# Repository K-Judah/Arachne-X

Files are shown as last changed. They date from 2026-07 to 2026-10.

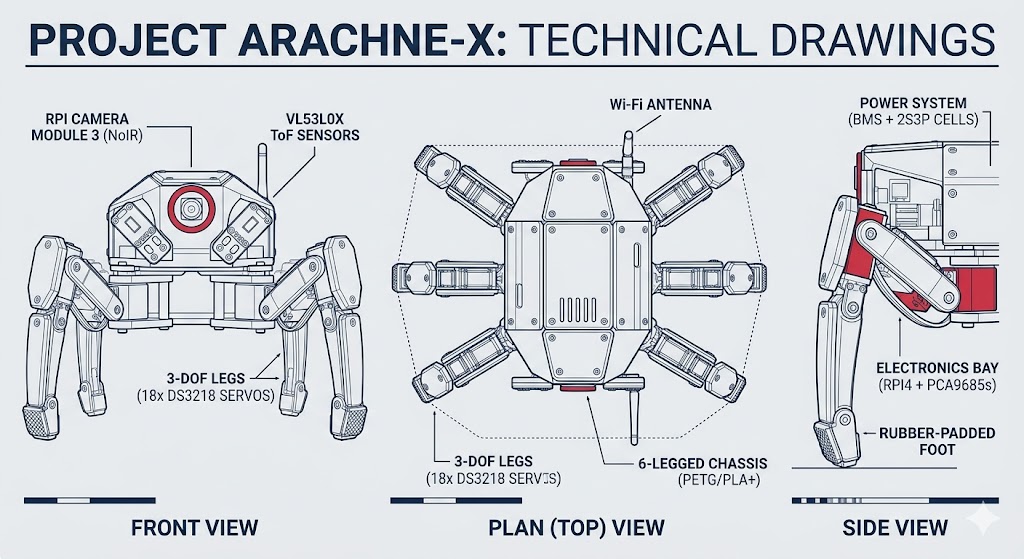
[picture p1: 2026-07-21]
Images/d1f36d08-249d-48b4-a907-852d1e6383c1.jpg

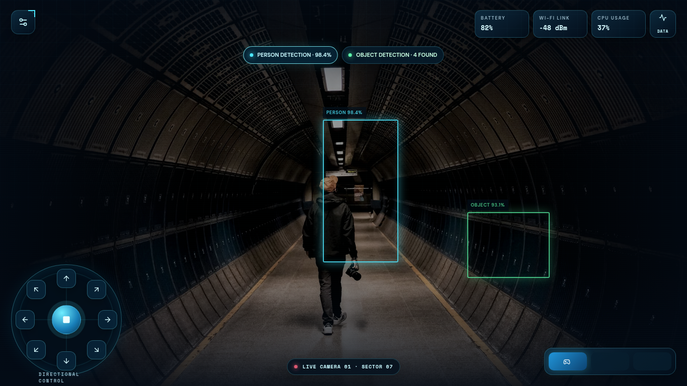
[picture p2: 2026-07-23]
Images/Arachne-X Futuristic Robotics App UI.png

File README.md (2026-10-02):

# Arachne-X

Arachne-X is a six-legged autonomous spider robot being developed as a long-term robotics and AI project.

## Goals

- Autonomous navigation
- AI vision
- Remote control
- Object detection
- Person tracking
- Computer vision
- Robotics research

## Hardware

- Raspberry Pi 4B
- ESP32-WROOM-32U based development board (exact board variant TBD)
- 2 PCA9685 servo controllers
- 18 MG996R servos: 6 legs with 3 DOF per leg
- Camera-based computer vision (camera model TBD)
- IMU and ToF sensors are planned options; selection and integration TBD

## Current Status

🚧 Single-leg prototype in development.

The July 24 progress log is historical: subsequent remote work added tibia and chassis models and updated coxa/femur and leg assembly assets. Their physical fit, range of motion and calibration still require verification. A [host-testable ESP32 firmware foundation](Firmware/README.md) provides joint configuration, validation and simulated actuator control. [Command/telemetry protocol v1](protocol/PROTOCOL.md) and a [Python reference client](Raspberry_Pi/README.md) now support simulated Pi/ESP32 exchanges. **Physical servo output is intentionally unavailable.** The repository also contains [OpenCV vision prototypes](Computer_Vision/README.md) and a [dashboard draft](Dashboard/dashboard.html). These are not connected to protocol v1; the dashboard uses a separate HTTP /cmd assumption, and vision steering labels are display output. Full Pi control services and gait/IK remain unimplemented.

## Software Planning

- [Proposed software architecture](docs/SOFTWARE_ARCHITECTURE.md)
- [Calibration records and simulated persistence](docs/CALIBRATION_RECORDS.md)
- [Repository audit and development plan](docs/DEVELOPMENT_PLAN.md)
- [Instructions for coding agents](AGENTS.md)

The hardware list above is the current planning baseline. Existing master specifications and mechanical documents retain historical DS3218/DevKit V1 references, and the old component list specifies one PCA9685. Those references need reconciliation with the current baseline; they do not establish compatibility with the evolving CAD. Mechanical dimensions, wiring, calibration and power-system values remain TBD until documented and validated.

## Team

### Judah
Project Founder & Lead Systems Engineer

Responsible for:
- System Architecture
- Mechanical Design
- Hardware Integration
- Project Management

### Bilaal
Co-Developer

Responsible for:
- Software Development
- Firmware
- AI
- Dashboard Development

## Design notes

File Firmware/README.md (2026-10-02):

# ESP32 firmware foundation

**Physical servo actuation is intentionally unavailable. This is not production-ready robot firmware.** No PCA9685, I2C, GPIO, PWM or transport driver exists. The ESP32 entry point constructs a disabled controller with unresolved configuration and returns. Building does not flash hardware, and PlatformIO upload targets are rejected. No hardware is needed for any test below.

The baseline is six three-joint legs, 18 MG996R servos and two PCA9685 controllers, with a Raspberry Pi 4B eventually supplying intent to an ESP32-WROOM-32U based board. The exact development board remains TBD. A hardware-independent [protocol v1](../protocol/PROTOCOL.md) now connects a [Python reference client](../Raspberry_Pi/README.md) to the host-tested C++ endpoint. Its component is registered for the ESP32 build but is not attached to a physical transport or boot task.

## Layout and build decision

```text
Firmware/
  platformio.ini          pinned ESP-IDF cross-compilation environment
  requirements-build.txt  pinned PlatformIO frontend
  CMakeLists.txt          host/ESP-IDF build selection
  control_core/
    include/arachne/      joint IDs, configuration, output/clock interfaces, actuator API
    src/                  portable validation and actuator implementation
  esp32/main/             inert app_main; no hardware drivers
  protocol/               bounded wire codec, transport interface and dispatcher
  calibration/            versioned record codec, persistence contract and host memory storage
  test/
    support/              fake output, fake clock, synthetic calibration, test runner
    test_control.cpp      simulation and validation tests
    test_locked.cpp       firmware-lock tests, including the actual app_main
  scripts/deny_upload.py  rejects PlatformIO upload/program targets
```

The existing architecture specifies ESP-IDF and separate esp32/control_core directories. We retain both, using PlatformIO as an ESP-IDF dependency/build frontend, not switching to Arduino. Host CMake/CTest compiles the same core without downloading an embedded SDK or a test framework. The Python reference client lives outside the firmware project in Raspberry_Pi/; a full Pi robot service is not implemented.

## Run host tests

Prerequisites: CMake 3.20 or newer, Python 3.11+ (standard library only) and a C++17 compiler (GCC/Clang, or Visual Studio C++ Build Tools and a Windows SDK). The host tests have no external library dependencies. From the repository root:

```sh
cmake -S Firmware -B Firmware/build-host -DARACHNE_HOST_TESTS=ON -DCMAKE_BUILD_TYPE=Release
cmake --build Firmware/build-host --config Release --parallel
ctest --test-dir Firmware/build-host -C Release --output-on-failure
```

On Windows, use a developer terminal if the tools are not on PATH. CMake can use its default Visual Studio generator; do not reuse a build directory generated for a different compiler. Use `ctest --test-dir Firmware/build-host -C Release -V` to see every named test case. Tests use runtime checks that remain active in Release builds, not C/C++ assertions removed by NDEBUG. Project sources and tests compile with warnings treated as errors.

`control_tests` links the simulation-enabled core; `locked_tests` separately compiles the same core with simulation disabled, exactly as firmware does. The latter proves that even complete synthetic configuration and a fake backend cannot enable the locked build. `protocol_tests` and `protocol_locked_tests` exercise the codec/dispatcher. A Python CTest entry runs unit tests and actual Python-to-C++ endpoint exchanges through two host-only bridge executables. Two additional suites, calibration_tests and calibration_locked_tests, cover persistence and restored-configuration safety, for seven suites total. See [calibration records](../docs/CALIBRATION_RECORDS.md) for the schema, lifecycle and validation results. Configuration also verifies that ESP32 flags combined with simulation enablement fail compilation for the expected guard diagnostic. The Python suite verifies the unchanged upload guard. The GitHub Actions workflow runs all host tests on Linux and Windows and separately cross-compiles the ESP32 application; no physical devices are used.

## Cross-compile only

Use Python 3.11 and install the pinned frontend in a virtual environment if PlatformIO is not already available:

```sh
python -m pip install -r Firmware/requirements-build.txt
pio run --project-dir Firmware --environment esp32_compile_only
```

The environment pins PlatformIO Core 6.1.19, Espressif32 platform 6.10.0, ESP-IDF package 3.50400.0 (ESP-IDF 5.4.0) and Xtensa compiler 14.2.0+20241119. First compilation downloads SDK/tool packages and requires internet access. Other build helpers are resolved by that platform release. See the [PlatformIO ESP-IDF build documentation](https://docs.platformio.org/en/latest/frameworks/espidf.html) and [pinned platform manifest](https://github.com/platformio/platform-espressif32/blob/v6.10.0/platform.json).

`esp32dev` is a generic ESP32 **compile-only surrogate**, not a claim that the installed board is a DevKit V1 or has the manifest's flash layout. No robot GPIO, I2C address, oscillator frequency or production calibration is assigned. Actual board/flash settings must be verified before a later deployment phase. Do not flash the generated image. Upload is intentionally blocked; direct external flashing tools are outside this project's safeguards.

## Joint identity and configuration

Strong enums define `Leg::{LF,LM,LR,RF,RM,RR}`, `JointKind::{Coxa,Femur,Tibia}` and all 18 logical `JointId` values, from `LF_Coxa` through `RR_Tibia`. `Unknown` is a rejected sentinel used by default-constructed records, not an additional joint. IDs follow the architecture's leg-major order; names such as `LF.coxa` are available for diagnostics. Bounds-checked helpers reject invalid leg/joint enums.

Each `JointConfiguration` links one logical ID to a `Wiring` record (controller A/B and channel) and a separate `Calibration` record. Configuration slot order does not determine identity. The only production factory, `unconfigured_robot()`, contains the 18 identities but leaves all wiring, direction, angles and pulses as `std::nullopt`, with `Uncalibrated` state. There is no guessed mapping or default calibration in firmware. The architecture's channel table remains a proposal, not installed wiring.

Calibration fields use explicit radians and microseconds: minimum angle, neutral angle/offset, maximum angle, minimum pulse, neutral pulse and maximum pulse, plus Normal/Inverted direction and calibration state. Neutral must lie strictly inside both ranges so the two interpolation segments are defined. `neutral_rad` is the logical joint coordinate at the measured neutral pulse; it is not implicitly zero. Inversion reverses pulse endpoints while preserving measured neutral. The controller rejects targets outside the calibrated logical range rather than silently clamping them.

`validate()` returns a bounded `ValidationReport`, with an error code, offending configuration slot where applicable, logical joint, and a human-readable `describe()` message. It reports missing/duplicate/invalid joints, missing/invalid controllers and channels, duplicate controller/channel pairs, missing calibration fields, uncalibrated/invalid state, invalid direction, non-finite values, reversed/equal ranges and neutral values outside the strict interior. The PCA9685's 0-15 channel domain is a device constraint, not a chosen harness assignment. The same channel number on A and B is valid. Any invalid joint blocks enabling the entire system.

Only test code contains a complete configuration. Its deliberately asymmetric numbers are **synthetic arithmetic fixtures, not MG996R pulse ranges or robot joint limits**. Test support is outside the firmware component and compilation rejects inclusion on ESP32. Geometry, I2C addresses, GPIO assignments, PWM frequency, mechanical limits and measured offsets all remain TBD; fields not consumed by this phase are deliberately absent rather than given misleading defaults. Geometry schemas and physical storage adapters remain future work before physical motion. The portable calibration record and simulated atomic persistence are implemented; all physical values remain unresolved.

## Safety boundary and interfaces

`ServoOutput` accepts a typed `PulseCommand` (logical joint, controller, channel, pulse in microseconds, monotonic timestamp). `Clock` supplies optional monotonic microseconds; unavailable time fails closed. `FakeOutput` records attempts/accepted commands and can inject failure; `FakeClock` supplies deterministic time. `DisabledOutput` rejects every write without touching hardware. This phase does not convert pulses to PCA9685 counters or configure PWM frequency.

`ActuatorSystem` copies configuration into an immutable snapshot. Construction and `start()` issue no output. State begins `Disabled`; only explicit `enable_simulation()` in a host simulation build can transition to `SimulationEnabled`. That method requires complete valid configuration, an explicitly simulated backend and an available clock. Enable itself sends nothing. `disable()` and `start()` block subsequent commands; they never move to neutral or replay a previous command.

Firmware builds contain no enabling path. Defining `ARACHNE_HOST_SIMULATION` together with ESP-IDF's `ESP_PLATFORM` produces a compile error. The host simulation target alone defines that macro. There is no runtime switch, calibration flag or configuration value that unlocks the ESP32 build. A backend reporting Physical or Unavailable is rejected even in simulation. Test fakes have no hardware dependencies.

Invalid direct actuator targets, invalid runtime backend domain, clock loss/rollback and failed writes latch `Fault`; subsequent commands and enable requests fail. Protocol preflight uses the side-effect-free `validate_target()` to reject an entire invalid request before actuator calls; `emergency_stop()` explicitly latches Fault. Start/disable cannot clear that fault. For a fresh offline test session, construct a new controller; a production recovery protocol is not yet implemented. The actuator API is single-thread-owned and must not be called concurrently. No timing loop, velocity limiter, physical watchdog, IK or gait is implemented. The protocol endpoint implements configurable communication/motion deadlines only when its owner polls/ticks it; those are not a physical watchdog.

Stopping future software writes is **not** a physical emergency stop, power disconnect or guarantee that an externally powered PCA9685 has stopped an old waveform. This phase must never be used to control powered actuators. OE/cutoff wiring and a measured stop policy are prerequisites for any future hardware driver.

## Future calibration

After the electrical design, cutoff circuit and actual harness are verified, support the mechanism and calibrate one joint at a time: confirm channel identity, establish neutral before fitting the horn, measure direction and conservative collision-free endpoints, and validate the installed joint. Never blindly sweep assumed MG996R endpoints. Record servo identity, CAD/geometry revision, measurement method and date; use the versioned calibration record and atomic storage contract to retain approved evidence. A durable physical storage adapter and a verified approval process remain future work. Servo/horn replacement or changed geometry invalidates the affected record. The current `Calibrated` enum is sufficient for synthetic tests, not evidence of physical certification.

## Foundation verification snapshot (commit 7d2f00e, 2026-10-02)

- Windows x64, CMake 4.3.1-msvc1, MSVC 19.51.36260.0: Release configuration and compilation passed with /W4 /WX; no compiler warnings or errors.
- CTest: 2/2 executables passed, comprising 33/33 control cases and 4/4 locked-build cases (37 total). The actual ESP32 entry-point source was also compiled and run against the locked host core.
- CMake's negative compile check rejected ESP32 plus simulation flags with the intended diagnostic. Five isolated Python checks of the upload guard accepted normal build targets and rejected upload/uploadfs/program without invoking devices.
- PlatformIO 6.1.19 cross-build was attempted but interrupted during the first Xtensa toolchain download (380,779,175-byte archive). A separate 1 MiB transfer took 83.5 seconds. No ESP32 image was compiled or verified; rerun the documented cross-build when the SDK/toolchain download is available. The CI workflow is committed but has not been run on GitHub in this session.
- Protected CAD/Assembly/Images/Videos files passed before/after SHA-256 comparison. No physical hardware was used. These results do not establish electrical, mechanical or real-time safety.

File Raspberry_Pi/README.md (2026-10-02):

# Raspberry Pi protocol reference client

This source-only Python 3.11+ package implements the hardware-independent [protocol v1](../protocol/PROTOCOL.md) client. It is not a robot service, planner, physical transport or actuator driver. It has no third-party runtime/test dependencies; no package installation is needed to test it.

`arachne_protocol/wire.py` supplies bounded COBS/CRC framing and a stream parser. `transport.py` defines the nonblocking transport contract and bounded in-memory pairs. `client.py` implements handshake, heartbeat, status, explicit simulation enable requests, disable, single/multi targets and E-stop. Clients never enable automatically or retry requests. Physical permission remains false and a response claiming otherwise is rejected.

Add `Raspberry_Pi/` to Python's import path, then supply an implementation of `Transport` to `Client`. A memory pair alone needs its peer to service requests; it does not simulate firmware by itself. The test harness runs the actual C++ endpoint instead of a second Python server model. The current synchronous client expects a serviced reply when it reads; async IO/deadline scheduling belongs in a later transport adapter.

The API is `hello()`, `heartbeat()`, `status()`, `enable()`, `disable()`, `set_joint(joint_id, radians)`, `set_multi([(joint_id, radians), ...])`, and `emergency_stop()`. Accepted command results expose `accepted`, `simulation_enabled`, and `physical_permission` separately. NACKs raise `RemoteError` with an `Error` code and state/fault outcome. No target values are suggested here because actual geometry, travel and calibration remain TBD.

Run all previous firmware tests, new protocol tests and Python/C++ integration tests from the repository root:

```sh
cmake -S Firmware -B Firmware/build-host -DARACHNE_HOST_TESTS=ON -DCMAKE_BUILD_TYPE=Release
cmake --build Firmware/build-host --config Release --parallel
ctest --test-dir Firmware/build-host -C Release --output-on-failure
```

The Python test command is also visible with `ctest --test-dir Firmware/build-host -C Release -N -V`. It needs paths to the two built protocol bridge executables; neither bridge connects to hardware. CTest limits the integration test duration. Physical transport, authentication, production timing, boot-session uniqueness and configuration revision persistence remain TBD.

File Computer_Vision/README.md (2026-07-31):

# ARACHNE-X Mk I Vision

> Computer Vision subsystem for the ARACHNE-X Autonomous Hexapod Robot.

---

## Overview

The ARACHNE-X Vision System is responsible for allowing the robot to perceive, interpret, and react to its environment in real time.

The long-term objective is to develop an autonomous vision system capable of:

- Object detection
- Object tracking
- Human detection
- Obstacle recognition
- Target following
- Autonomous navigation
- Integration with the robot's AI system

Development is currently being carried out in Python using OpenCV before deployment onto the Raspberry Pi.

---

# Current Features

## Camera Initialisation

- Webcam initialisation
- Camera availability checking
- Live video streaming
- Graceful shutdown

---

## Vision HUD

A custom Heads-Up Display (HUD) was developed featuring:

- ARACHNE-X Mk I title
- FPS counter
- Camera resolution
- Camera status
- Operator name
- Central aiming reticle

---

## Frame Processing

Each captured frame is processed in real time by:

1. Capturing image
2. Converting BGR → HSV colour space
3. Detecting selected colours
4. Finding object contours
5. Drawing object boundaries
6. Calculating object centre
7. Estimating object position
8. Producing steering decisions

---

## Colour Detection

Implemented colour-based object detection using HSV filtering.

Current supported colour:

- Red

Processing pipeline:

```
Camera
    ↓
Capture Frame
    ↓
Convert BGR → HSV
    ↓
HSV Thresholding
    ↓
Binary Mask
```

---

## Object Detection

Implemented contour-based object detection using:

- `cv2.findContours()`
- `cv2.boundingRect()`
- `cv2.contourArea()`

Each detected object displays:

- Bounding box
- Object centre
- Object coordinates

Small contours are filtered to remove image noise.

---

## Object Tracking

For each detected object:

- Calculate centre coordinates
- Display coordinates
- Draw centre marker

Example:

```
Object Centre:
(318, 241)
```

---

## Robot Steering Logic

The vision system compares the detected object's centre with the camera's centre.

```
Error = Object X - Frame Centre X
```

Based on this error, the robot decides whether to:

- Turn Left
- Turn Right
- Go Straight

Current steering thresholds:

```
Error > 40      → Turn Right
Error < -40     → Turn Left
Otherwise        → Go Straight
```

---

## Current Vision Pipeline

```
Camera
    │
    ▼
Capture Frame
    │
    ▼
Convert to HSV
    │
    ▼
Create Colour Mask
    │
    ▼
Find Contours
    │
    ▼
Remove Noise
    │
    ▼
Calculate Bounding Box
    │
    ▼
Find Object Centre
    │
    ▼
Compare With Camera Centre
    │
    ▼
Determine Steering Direction
    │
    ▼
Display HUD
```

---

# Technologies Used

- Python 3.14
- OpenCV
- NumPy

---

# Current Project Structure

```
Computer_Vision/

│
├── Lessons/
│   ├── Camera_Test.py
│   ├── Pixel_Reader.py
│   ├── HSV_Explorer.py
│   ├── Colour_Detection.py
│   ├── Object_Tracking.py
│   └── MkII_Vision.py
│
├── Images/
│
├── Videos/
│
└── README.md
```

---

# Future Development

The following features are planned:

## Motion Detection

- Background subtraction
- Intruder detection
- Patrol mode

---

## Face Detection

- Human face recognition
- Operator tracking

---

## AI Object Detection

Integration of YOLO for detection of:

- Person
- Backpack
- Bottle
- Chair
- Laptop
- Phone
- Door
- Animals
- Vehicles

---

## Multi-Object Tracking

Track multiple objects simultaneously.

---

## Depth Estimation

Estimate target distance using camera vision.

---

## Raspberry Pi Deployment

Port the complete vision system to the Raspberry Pi onboard computer.

---

## Robot Integration

Connect vision output to:

- ESP32 controller
- Servo control system
- Navigation system
- AI decision engine

---

# Long-Term Goal

The ARACHNE-X Vision System will eventually serve as the robot's primary perception module, enabling autonomous exploration, obstacle avoidance, object recognition, and intelligent interaction with its surroundings.

---

## Project Status

**Current Stage:** Early Development (Mk II Vision)

### Completed

- Camera interface
- Live HUD
- HSV colour processing
- Colour segmentation
- Contour detection
- Bounding boxes
- Object tracking
- Steering decision logic

### In Progress

- Motion detection
- Human detection
- AI object recognition

---

Developed as part of the **ARACHNE-X Autonomous Hexapod Robot Project**.

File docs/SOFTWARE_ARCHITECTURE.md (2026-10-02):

# Proposed software architecture

Status: architecture proposed 2026-10-02; the [firmware foundation](../Firmware/README.md) implements portable joint/configuration validation and host-only simulated actuator control. [Protocol v1](../protocol/PROTOCOL.md) now implements a bounded command/telemetry codec, dispatcher and Python reference client. The ESP32 application remains inert and physical output is unavailable. Gait, IK, hardware drivers and full Pi services below remain proposals. See [development plan and repository audit](DEVELOPMENT_PLAN.md) for evidence and sequencing. Existing Documents/ files remain engineering history; this proposal uses the hardware assumptions supplied for the audit.

## Hardware and configuration contract

| Item | Current baseline |
| --- | --- |
| Legs and joints | 6 legs, coxa yaw / femur pitch / tibia pitch; 18 joints |
| Actuators | 18 MG996R servos |
| High-level computer | Raspberry Pi 4B |
| Low-level computer | ESP32-WROOM-32U based development board; exact board/pinout TBD |
| PWM controllers | 2 PCA9685 boards; actual addresses and wiring TBD |
| Vision | Camera-based; camera model, interface and calibration TBD |
| Mechanics | Evolving CAD; link lengths, mounting transforms, joint zeros and motion envelope TBD |
| Power and sensing | Rails, battery, current budget, cutoff circuit, IMU/ToF selection and feedback sensors TBD |

PETG, M3 hardware and a below-5-kg target appear in the historical mechanical requirements. They are design requirements, not measured properties of a completed MG996R robot. Servo fit, torque/load capacity and clearances require revalidation. Do not infer link lengths from filenames or use generic servo travel/pulse specifications as calibration.

## Responsibilities and data flow

```text
Browser dashboard <-> Pi API / telemetry service <-> command arbiter
Camera -> vision worker -> timestamped observations -> mission controller
Mission controller ---------------------------------> command arbiter
command arbiter <-> serial link <-> ESP32 protocol / safety supervisor
                                   -> gait -> foot targets -> leg IK
                                   -> joint limiter -> calibration -> PCA9685 x2
                                   -> 18 servos
```

The Pi sends bounded motion intent, not continuous PWM writes. The ESP32 maintains timing and independently rejects unsafe/stale requests. Vision cannot directly drive motors. Manual and autonomous sources share one exclusive control lease; stop/fault handling overrides both. A Pi crash must not leave an indefinite command active.

Proposed stack: ESP-IDF with C++ portable control components on ESP32; Python packages for Pi services and vision; TypeScript browser UI. Select and pin supported versions when scaffolding, after confirming the exact board and Pi OS. Start with simple processes and typed contracts; defer ROS integration until navigation needs justify it.

## Proposed repository layout

```text
Firmware/esp32/           ESP-IDF application, board adapters, component tests
Firmware/control_core/   portable safety, kinematics, gait and joint logic
Raspberry_Pi/            Python command arbiter, serial client, API and missions
Computer_Vision/         camera adapters, inference workers, replay and evaluation
Dashboard/              browser application and UI tests
protocol/               versioned wire specification, schemas and golden vectors
config/                 geometry, wiring and calibration schemas/examples
simulation/             fake plant, visualizer and scenario runner
tests/integration/      Pi/ESP32 contract and fault-injection scenarios
docs/                   software decisions, setup and validation procedures
Documents/              existing engineering records (preserved)
```

The audit created docs/. The firmware foundation added Firmware/esp32/, Firmware/control_core/ and Firmware/test/, with PlatformIO wrapping the specified ESP-IDF framework and CMake/CTest for independent host tests. The generic ESP32 build target is compile-only until the exact board is identified; physical enable is compiled out. The [calibration record schema and simulated persistence](CALIBRATION_RECORDS.md) are implemented. Geometry schemas, physical storage adapters and the complete safety state machine remain future work. Keep existing Ai/ and Feature/ placeholders until a separate consolidation change. Avoid parallel implementations in Ai/ and Computer_Vision/.

## ESP32 firmware and PCA9685 output

Use a fixed-period motion task driven by a monotonic clock. Its period, command refresh budget and watchdog thresholds are TBD until measured. Protocol parsing and telemetry run outside the motion task with bounded queues and payload sizes. Never block motion on logging or network activity. One component owns I2C; report write failures and deadline misses to the safety supervisor.

The pipeline accepts a desired body motion/posture, updates gait phase, computes six foot targets, solves IK, checks all 18 joints, applies rate limits, then converts angles to calibrated pulse widths. Reject an invalid full target before any output writes. Stage a complete output frame; two boards cannot be assumed to update atomically, so measure skew and fault on partial-write failure rather than reporting successful motion.

The PCA9685 adapter owns board discovery against configured identities, frequency setup, pulse-to-counter conversion and output-enable behavior. Account for measured oscillator/frequency error. Servo PWM frequency and approved pulse bounds are TBD bench values. Keep PWM carrier frequency separate from gait/control update frequency. Do not silently remap channels when a board is missing. Unused channels stay disabled. Proposed OE gating needs verified wiring and a defined boot/reset state before hardware tests; disabling PWM is not the same as disconnecting servo power.

## Stable 18-joint mapping

Use the robot's forward direction, never the camera image, to name left/right. Proposed IDs are stable software identities. This table is a proposed harness allocation, not verified wiring; addresses, pinouts, polarity and installed mapping remain TBD until continuity and single-joint tests pass. Each controller uses nine channels so all three joints of a leg remain together.

| Leg | IDs: coxa, femur, tibia | Proposed board | Proposed channels |
| --- | --- | --- | --- |
| Left front (LF) | 0, 1, 2 | A | 0, 1, 2 |
| Left middle (LM) | 3, 4, 5 | A | 3, 4, 5 |
| Left rear (LR) | 6, 7, 8 | A | 6, 7, 8 |
| Right front (RF) | 9, 10, 11 | B | 0, 1, 2 |
| Right middle (RM) | 12, 13, 14 | B | 3, 4, 5 |
| Right rear (RR) | 15, 16, 17 | B | 6, 7, 8 |

Use names such as LF.coxa in configuration and logs. Validate exactly 18 unique joints, unique board/channel pairs, valid channel ranges, two distinct configured board identities and complete per-joint calibration. Channels 9-15 on each board are reserved/disabled. Do not assume mirrored legs have identical servo signs.

## Calibration and geometry

The current portable calibration subset is specified in [CALIBRATION_RECORDS.md](CALIBRATION_RECORDS.md): CRC-checked records, explicit revision/provenance checks, staged atomic publication and immutable snapshots. Existing actuator and protocol guards are unchanged; storage operations disarm and never auto-enable. The wider geometry and physical calibration process below remains future work.

Separate three versioned configuration records:

- Geometry: robot/CAD revision, source measurements, three link lengths, six body-to-leg transforms, joint axes, zero conventions, permitted workspace and collision constraints. Physical values TBD.
- Wiring: board identities/addresses, ESP32 pin assignments, named joint-to-channel map and output-disable wiring. Physical values TBD.
- Calibration: servo identity and installed joint, direction, neutral offset, validated angle-to-pulse points, pulse and angle bounds, velocity/acceleration limits, date and method. Physical values TBD.

Prefer a measured monotonic piecewise-linear angle-to-pulse curve when a simple offset/scale is inadequate. Reject non-finite, non-monotonic or incomplete records. Validate the configuration offline and again on the ESP32; transmit an immutable version/hash and refuse arm on mismatch. Persist validated records atomically with integrity checks; interrupted writes must leave a previous valid record or a disarmed fault, never partial calibration.

Calibration is a deliberate service mode: support the mechanism, verify supply/cutoff and channel identity, operate one joint at a time with restricted pulses, establish neutral before horn attachment, measure direction and conservative usable endpoints, then verify the installed joint without collision. Never sweep blindly to physical stops. Replacing a servo/horn or changing CAD invalidates affected calibration/geometry until rechecked. Raw PWM commands are excluded from normal operation.

## Kinematics and gait

Proposed body frame: right-handed, +X forward, +Y left, +Z up; use metres, radians, seconds and explicit frame IDs. Define each leg frame at its coxa mount using a configured rigid transform. Define positive joint angles by the right-hand rule about documented joint axes; servo electrical direction belongs in calibration.

Provide pure forward/inverse kinematics functions with geometry inputs and structured results: solution, unreachable, singular or joint-limit violation. A yaw plus planar two-link analytic solver is appropriate only after CAD confirms that geometry; otherwise use a model matching measured offsets/axes. Choose the solution branch nearest the previous valid pose with continuity constraints. Never hide unreachable targets by broadly clamping trigonometric arguments; allow only documented floating-point tolerance. Reject invalid motion and enter the tested stop policy. Test FK/IK round trips, mirror transforms, workspace edges, singularities and branch continuity using synthetic fixtures clearly separated from physical configuration.

Gait generation owns stance/swing scheduling, phase, bounded foot trajectories and transitions between stand, controlled stop and walking. Start with a slow crawl and explicit support-margin checks using a measured or conservatively bounded centre of mass; that value is TBD. Add tripod gait only after stability testing. Speed, step length, clearance, duty factor and body height are validated configuration, all TBD for hardware. Interpolate transitions; do not jump between gait poses. Quasi-static support checks do not prove dynamic stability or actual foot contact.

## Safety state machine

Proposed states: BOOT -> DISARMED -> READY -> ARMED, with CALIBRATION entered explicitly from DISARMED and FAULT latched from any state. READY means configuration, required devices and session handshake are valid; ARMED additionally requires an explicit operator request and a fresh control lease. Boot and reset keep outputs disabled. Leaving FAULT requires the cause to clear, explicit acknowledgement and a new arm sequence.

Validate finite values, units, limits, command age, sequence, mode and configuration before acceptance. A motion-command expiry, link loss, repeated deadline miss or driver failure triggers local fault handling even if heartbeat traffic continues. A heartbeat alone never refreshes motion intent. Reject malformed frames without refreshing any lease.

Distinguish controlled stop (bounded deceleration into a validated supported pose), output disable, and physical power cutoff. The appropriate fallback depends on support and power; disabling servos may collapse the chassis. A stop profile, maximum hold duration, escalation policy and timeouts are TBD and block loaded walking until bench-tested. Loss of trustworthy output control uses the verified hardware disable/cutoff path. Software cannot guarantee cutoff without that circuit. Never resume the last gait after reconnect.

## Pi to ESP32 communication

The implemented joint-command subset is specified in [protocol/PROTOCOL.md](../protocol/PROTOCOL.md), which governs its exact v1 wire format, message names, timeout settings and E-stop behavior. It uses COBS/CRC16, sessions, increasing request IDs, receiver-issued tokens, and an owner-assigned configuration revision. Physical permission is always false. The Python reference client and C++ endpoint communicate only through simulated transports in tests. The broader motion-intent/Pi-service proposal below remains future work; v1 deliberately has no gait/motion-intent messages. Production session uniqueness, revision persistence, physical transport and timeout measurements remain TBD.

Propose wired serial, initially USB serial through the development board if supported; direct UART is an alternative after voltage levels, pinout and grounding are verified. Connector, baud rate and wiring are TBD. Transport adapters must allow offline loopback and replay.

Before implementation, freeze a versioned bounded binary frame: delimiter-safe framing (proposed COBS), protocol version, message type, payload length, boot/session ID, sequence, request ID, payload and CRC. Exact field widths, byte order, CRC parameters, maximum frame size and golden bytes must be specified in protocol/ before parser work. CRC detects corruption; it is not authentication.

Define HELLO/CAPABILITIES, CONFIG_STATUS, ARM, DISARM, STOP, MOTION_INTENT, HEARTBEAT, ACK/NACK, TELEMETRY and FAULT messages. Motion intent includes velocity/posture/gait and a bounded validity interval; use ESP32 monotonic receive time for local expiry, not unsynchronized Pi wall time. Add a receiver-issued freshness token with an ESP32 deadline so delayed previously unseen packets cannot gain a fresh lease simply by arriving late. Session IDs and sequences reject replay, duplicates and out-of-order commands. Negotiate protocol/configuration compatibility before enabling commands. Handshake or reboot invalidates old sessions and pending commands.

ACK identifies acceptance/rejection and reason; acceptance is not physical completion. Retry only operations with defined idempotency, deduplicated by request ID; do not replay queued motion after recovery. Keep only the latest valid motion intent. STOP has priority over queued movement. Report rejected commands and expiries. Bound parser memory, resynchronize after corrupt/truncated data, and rate-limit diagnostics. Authentication of remote operators belongs at the Pi API; serial access remains restricted to the robot service.

## Pi services, vision and dashboard

The integrated remote work includes OpenCV experiments in Computer_Vision/ and Dashboard/dashboard.html. Preserve these prototypes: vision currently displays steering labels, and the dashboard assumes direct HTTP /cmd requests to an ESP32 host. Neither is connected to protocol v1 or the proposed Pi API below. Existing camera indices, thresholds and draft HTTP settings are prototype choices, not verified robot configuration. The following service design remains a proposal.

Run a supervised robot service with separate command arbiter, serial adapter, telemetry cache and API components. Restart into a non-driving state. Mission logic supplies intent only while its exclusive lease is valid; operator override cancels that lease. Persist structured events with bounded storage, session IDs and timestamps. Keep camera/inference in a separate worker so slow inference cannot stall control or telemetry.

Vision stages: camera capture -> timestamped frame -> optional preprocessing -> detector -> tracker -> observations. Use bounded latest-frame queues and drop stale frames. Camera intrinsics/extrinsics, detector/model, input resolution, inference runtime and frame-rate target are TBD after Pi 4B profiling. Keep frame timestamps/IDs on detections, confidence and tracking metadata. Monocular detections alone do not establish metric distance; report distance unavailable unless a calibrated method supports it. Test against recorded clips before autonomous behavior. Model artifacts need provenance, licensing and evaluation records; no model downloads are part of this audit.

The dashboard connects only to the Pi: HTTP for configuration/status operations, WebSocket for telemetry and control-lease updates, and a separate camera stream whose transport is selected after latency measurements. Provide authentication, command authorization and deployment guidance before remote control; limit initial service exposure to an explicitly configured local network. Browser disconnect and tab inactivity must expire the operator lease independently of Pi-to-ESP32 health.

Telemetry includes ESP32 uptime, state/fault, command age, configuration hash, controller errors, gait phase, commanded joint angles, Pi health, camera status and timestamped detections. Attach units, source and freshness. Label joint positions as commanded and foot positions as model-estimated unless sensors measure them. Battery percentage/runtime/current and servo health remain unavailable until sensing and estimation are validated. UI mockups in Images/ are concepts, not working features. Never display unknown subsystems as healthy by default.

## Simulation, testing and reproducibility

Use one portable motion implementation in firmware and host simulation to avoid divergent IK/gait algorithms. Start with kinematic visualization and a fake servo/I2C/clock backend; add dynamics only when mass, inertia, friction and actuator models are measured. Synthetic dimensions belong only in named test fixtures and cannot arm hardware. CAD is input reference material, not something tests rewrite.

Plan host tests for configuration rejection, all 18 mappings, pulse conversion/bounds, IK/FK, gait continuity and the safety state machine. Use shared protocol golden vectors on Pi and ESP32, parser fuzzing and fault injection for malformed/oversized frames, loss, duplicates, latency, reboot, clock behavior, partial I2C writes and stale vision/operator commands. Integration tests must show automatic motion does not resume after failure. Separate simulated behavior from physical evidence.

Add pinned build manifests, Python dependency metadata, frontend lockfile, documented commands and CI when each component is introduced. CI should build ESP32 firmware, run portable control/Pi tests, validate contracts/configuration, and later lint/type-check/test the UI. Hardware tests are opt-in bench procedures, never default CI. Archive configuration revision, software revision, test conditions and results for every physical milestone.

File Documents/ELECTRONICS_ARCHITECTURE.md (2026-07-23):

Dashboard
    ->
Raspberry Pi
    ->
ESP32
    ->
PCA9685
    ->
Servos

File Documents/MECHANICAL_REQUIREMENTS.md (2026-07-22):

# Mechanical Requirements

## Scope

This document defines the mechanical baseline for Arachne-X, a six-legged autonomous spider robot. It complements the project master specification and governs mechanical design, CAD, fabrication, assembly, and serviceability decisions.

## System Definition

| Requirement | Value |
|---|---|
| Robot type | Hexapod spider robot |
| Number of legs | 6 |
| Degrees of freedom per leg | 3 |
| Total servos | 18 |
| Servo model | DS3218 |
| Structural material | PETG |
| Fasteners | M3 hardware |
| Manufacturing method | FDM 3D printing |
| Target assembled weight | Under 5 kg |

Each leg shall comprise a coxa, femur, and tibia joint. Each joint shall be driven by one DS3218 servo.

## Dimensional Constraints

- The six leg mounting locations shall be arranged symmetrically about the body centerline, with three mounting locations on each side.
- Each leg shall provide three non-interfering rotary axes: coxa yaw, femur pitch, and tibia pitch.
- Final link lengths, body footprint, and stance height shall be defined in CAD before fabrication and shall support a stable standing pose without leg-to-leg, leg-to-body, or foot-to-body interference throughout the intended gait envelope.
- All dimensions that interface with DS3218 servos shall be verified against the physical servos used for the build. CAD shall not rely solely on marketplace dimensions or generic servo models.
- Servo pockets shall provide a minimum 0.5 mm assembly clearance around the measured servo envelope, except at positive locating features.
- Printed holes intended for M3 fasteners shall be designed at 3.2 mm nominal diameter unless a different post-processing method is explicitly documented.
- Clearances for moving parts shall be at least 0.5 mm after accounting for FDM dimensional variation.
- Cable passages shall be sized to allow installation and removal of the specified cable and connector without cutting, pinching, or excessive bending.
- The body shall include a protected internal electronics bay sized for the Raspberry Pi 4B, ESP32 DevKit V1, PCA9685 servo drivers, power-distribution hardware, connectors, and service access. Final bay dimensions shall be documented in CAD and validated against the actual selected hardware.
- The completed robot, including battery and all electronics, shall remain below 5 kg.

## Structural and Assembly Requirements

- The frame shall be printed in PETG and shall use M3 hardware for removable structural joints and electronics mounting where practical.
- Load-bearing servo mounts shall restrain each DS3218 servo against rotation and translation without relying on the servo output shaft or mounting screws alone.
- Leg segments shall transfer operating loads through the printed structure and M3 fasteners; servo output shafts shall not be used as the sole structural support for a joint.
- Every leg shall be replaceable independently of the other five legs.
- Leg removal shall not require disassembling the central body, removing unrelated legs, or cutting cable ties.
- The robot shall include a modular electronics bay with removable covers or modules for the Raspberry Pi, ESP32, PCA9685 boards, power system, and wiring interfaces.
- Assembly shall use a documented fastener schedule identifying fastener type, length, quantity, and location.
- Threaded connections in printed plastic shall use captive nuts, heat-set inserts, or other documented reinforcement where repeated service is expected.
- Assembly shall allow neutral-position servo calibration before final horn attachment and shall provide access to servo horn screws.

## Printability Requirements

- Parts shall be manufacturable by FDM 3D printing in PETG without unsupported enclosed features that cannot be cleaned or inspected.
- Each part shall specify its intended print orientation, layer height, infill, wall count, supports, and post-processing requirements in the manufacturing documentation.
- Load-bearing parts shall orient layers to reduce the risk of delamination under expected bending and torsional loads.
- Design features requiring bridges, supports, or tolerance-critical holes shall be validated with a small print before full production.
- Sharp internal corners in load-bearing members shall be avoided or relieved with fillets to reduce stress concentration.
- Large parts shall be split into printable sections only when the resulting joints maintain structural rigidity and remain serviceable.
- Parts shall include identification markings or a documented naming convention to prevent left/right and leg-position assembly errors.

## Cable Routing and Electronics Requirements

- Signal and power wiring shall route internally through the body and, where practical, through protected leg paths.
- Cable routing shall avoid moving joint pinch points, sharp edges, hot surfaces, and high-strain locations.
- Wiring shall include strain relief at body exits, servo interfaces, and electronics-bay entries.
- Power wiring shall be separated from sensitive signal wiring where practical to reduce electrical noise.
- Covers and cable guides shall be removable with M3 hardware for inspection and repair.
- Wiring paths shall preserve adequate bend radius for the installed cable and connectors.

## Maintenance and Serviceability Requirements

- Servos, servo horns, fasteners, electronics modules, battery connections, and cable routing shall be accessible with standard hand tools.
- A failed servo shall be replaceable without destructive disassembly of printed parts.
- Components subject to wear, impact, or frequent adjustment shall be replaceable as individual modules.
- The design shall permit inspection of fastener tightness, cable condition, servo mounting, and printed-part cracking without full robot teardown.
- Service documentation shall include exploded views, wiring routes, part numbers, print files, fastener schedule, and servo calibration procedure.
- After maintenance, the robot shall support repeatable reassembly to the documented neutral pose and leg geometry.
- Design revisions shall preserve backward-compatible interfaces where practical, especially for replaceable legs and electronics-bay modules.

## Acceptance Criteria

A mechanical revision is acceptable when it:

1. Uses six three-degree-of-freedom legs and 18 DS3218 servos.
2. Is fabricated primarily from PETG FDM-printed parts with M3 hardware.
3. Keeps the fully assembled robot under 5 kg.
4. Provides a replaceable-leg design, modular electronics bay, internal cable routing, and serviceable components.
5. Demonstrates non-interfering joint motion in the intended operating range.
6. Provides documented assembly, print, calibration, and maintenance instructions.

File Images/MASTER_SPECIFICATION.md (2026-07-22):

# Arachne-X

Arachne-X is a six-legged autonomous spider robot designed for robotics, embedded systems, AI, computer vision, and autonomous navigation research.

The project is being developed by a Mechatronics Engineering student as a long-term engineering portfolio and learning platform.

## Vision

Build a spider robot capable of:

- Walking autonomously
- Remote wireless operation
- Real-time video streaming
- Person detection
- Object detection
- Target tracking
- Environmental sensing
- Future autonomous patrol missions

## Hardware

### Processing

- Raspberry Pi 4B
- ESP32 DevKit V1

### Motion

- DS3218 Servos
- PCA9685 Servo Drivers

### Vision

- Raspberry Pi Camera Module 3

### Power

- LiPo Battery System

### Structure

- PETG 3D Printed Frame
- M3 Fasteners

## Leg Architecture

Each leg consists of:

1. Coxa
2. Femur
3. Tibia

Each joint is actuated by a DS3218 servo.

Total:

6 Legs
18 Servos

Phone / Laptop
        │
        ▼
Web Dashboard
        │
        ▼
Raspberry Pi 4B
        │
        ▼
ESP32
        │
        ▼
PCA9685
        │
        ▼
Servos

Dashboard & Control System
Overview

Arachne-X will be operated through a custom web-based command center accessible from a phone, tablet, or computer over Wi-Fi.

The dashboard serves as the primary interface between the operator and the robot, providing real-time control, visual feedback, telemetry monitoring, and autonomous mission management.

The dashboard is inspired by modern military, aerospace, and autonomous robotics control systems.

Live Camera Feed
Purpose

Provide real-time visual awareness of the robot's surroundings.

Features
Low-latency video stream from Raspberry Pi Camera Module 3
Full-screen viewing mode
Adjustable video quality
Daylight and low-light operation
Future support for night vision camera modes
Display Information
Camera status
Frame rate (FPS)
Resolution
Connection quality
Person Detection
Purpose

Identify and highlight humans within the camera's field of view.

Features
Real-time detection using AI computer vision
Bounding box overlay around detected people
Confidence percentage display
Multiple-person tracking
Detection logging
Example Display
PERSON DETECTED
Confidence: 98.4%
Distance: Estimated
Tracking: Active
Future Expansion
Facial recognition experiments
Known vs unknown person identification
Follow-person mode
Object Detection
Purpose

Detect and classify objects within the environment.

Features
Real-time object recognition
Bounding box overlays
Confidence scores
Multiple object support
Example Objects
Chairs
Tables
Bags
Vehicles
Animals
Electronics
Obstacles
Future Expansion
Custom object training
Mission-specific object detection
Threat identification
Battery Monitoring
Purpose

Monitor robot power levels and prevent unexpected shutdowns.

Dashboard Information
Battery percentage
Battery voltage
Estimated remaining runtime
Charging status
Power consumption trends
Warning Levels
Green
Battery > 60%
Yellow
Battery 30% - 60%
Red
Battery < 30%
Emergency Actions

Future versions may:

Return to home position
Enter low-power mode
Disable non-critical systems
Manual Control System
Purpose

Allow direct operator control of robot movement.

Controls
Directional Movement
Forward
Backward
Strafe Left
Strafe Right
Rotation
Rotate Left
Rotate Right
Speed Modes
Slow
Normal
Fast
Posture Controls
Stand
Sit
Crouch
Raise Body
Lower Body
Emergency Functions
Stop All Motion
Servo Disable
Reboot System
Autonomous Mode
Purpose

Allow the robot to operate without continuous user input.

Modes
Patrol Mode

Robot follows predefined routes.

Follow Mode

Robot follows a selected target.

Observation Mode

Robot remains stationary while monitoring surroundings.

Exploration Mode

Robot investigates unknown areas.

Return Home Mode

Robot navigates back to a predefined starting position.

Future Modes
SLAM Navigation
Autonomous Mapping
Security Patrol Missions
Search and Inspection Operations
Telemetry System
Purpose

Provide real-time robot status information.

Displayed Metrics
Power
Battery percentage
Battery voltage
Power draw
Processing
Raspberry Pi CPU usage
Raspberry Pi temperature
Memory usage
Connectivity
Wi-Fi signal strength
Network latency
Connection quality
Motion
Walking speed
Current gait
Servo status
Leg positions
Vision
Active detections
Camera status
AI processing load
System Health

Display:

SYSTEM STATUS: ONLINE

Motors: OK
Vision: OK
Network: OK
Battery: OK
Navigation: OK
Long-Term Goal

The dashboard should eventually function as a complete command center for Arachne-X, enabling:

Manual operation
Autonomous operation
Real-time monitoring
AI-assisted navigation
Mission planning
Data collection
Future multi-robot coordination

This interface will serve as the primary control hub for all current and future versions of the Arachne-X platform.

Phase 1
Single Leg Prototype

Phase 2
Full Leg Validation

Phase 3
Body Design

Phase 4
Six-Leg Assembly

Phase 5
Vision Integration

Phase 6
AI Detection

Phase 7
Autonomous Navigation

Completed

- Initial concept
- Hardware selection
- Dashboard concept
- Leg CAD v1

In Progress

- Mechanical redesign
- Hardware integration
- Repository setup

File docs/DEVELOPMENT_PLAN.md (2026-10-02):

# Repository audit and development plan

## Calibration persistence follow-up (2026-10-02)

From synchronized main 4d14f5317edad2339ed38934f25a12bffd339b41, the hardware-independent [calibration-record lifecycle](CALIBRATION_RECORDS.md) is implemented: bounded schema v1, CRC-32, complete configuration validation, external revision and approval-claim metadata, staged atomic publication, host memory storage and fault injection. All 97 previous cases remain; 34 calibration cases bring the total to 131 across seven passing Release suites. Physical output and upload guards remain locked. The existing wire protocol, remote prototypes and engineering assets are unchanged.

The simulated persistence recommendation below is now complete. Real calibration, evidence verification, revision assignment and physical storage durability remain unresolved. The next recommended phase is a host-only calibration inspection/review tool that displays record diagnostics and provenance without approving data or enabling motion. No such tool, geometry, IK, gait or hardware driver is implemented in this phase.

## Remote integration (2026-10-02)

The three local development changes were replayed onto remote main ee7eb541da199c8d636743de5a2dd22bb56c62e3, preserving its 69 commits since a94bafa. Remote changes have no file overlap with the local commits: CAD/Assembly revisions and additions, six OpenCV scripts plus their README, and Dashboard/dashboard.html remain unchanged. Documents/, Electronics/, firmware, root README, AGENTS.md, docs/ and CI had no remote changes in that interval.

The remote tree now includes tibia/chassis models and updated leg assemblies; file presence does not establish mechanical validation. OpenCV prototypes provide camera/HUD, HSV/colour, contour/motion and displayed steering experiments. The dashboard draft sends HTTP /cmd requests directly to an assumed ESP32 host; it has no implemented backend here and is not compatible with protocol v1. Both prototypes are preserved, not wired into control or exercised against hardware. Future integration must follow the safety boundaries without assuming those draft endpoints or camera settings are production choices.

The inventory, CAD counts and findings below describe a94bafa only, not the integrated tree. The original local development chain remains on backup/codex-protocol-f7af828. No new development phase is part of this integration.

Integration validation: a fresh MSVC Release build passed with /W4 /WX and all 97 cases across five CTest suites passed (33 control, 4 locked, 29 protocol, 2 protocol-locked, 29 Python/integration). Compile-conflict and upload guards passed. All 29 protected remote files matched Git blob hashes; remote vision/dashboard and engineering documents were unchanged. All 21 local links in the integration/development documentation passed. ESP32 cross-compilation remains unverified because the toolchain is absent. The initial Windows build environment required duplicate PATH normalization and sandbox access for MSBuild FileTracker; no project build changes were needed. CMake reported only the expected unused CMAKE_BUILD_TYPE option for the multi-configuration Visual Studio generator; Release was selected explicitly at build/test time.

## Protocol follow-up

The phase after 7d2f00e implements [protocol v1](../protocol/PROTOCOL.md): bounded COBS/CRC framing, a portable ESP32 parser/dispatcher, simulated transport, configuration-aware target preflight, atomic multi-target validation, explicit simulation enable, E-stop latch, configurable liveness/freshness deadlines, status telemetry and a stdlib-only Python reference client. Tests exchange bytes with the actual C++ endpoint in both simulation and locked builds. Physical-output and upload guards remain unchanged. No physical link, gait, IK or Pi robot service is added.

Phase 2's host protocol subset is implemented; real service deployment, authentication, session-seed/revision persistence and measured timings remain future work. The prior cross-build gate remains outstanding because the SDK/toolchain is absent; per this phase's instructions, the slow download is not repeated. Before any hardware phase, close that build gate and verify board identity, power/cutoff and mapping/calibration. The next implementation phase is a simulated calibration-record lifecycle: versioned serialization, integrity checks and atomic persistence tests, retaining the physical-output lock until electrical/mechanical prerequisites are resolved.

## Firmware foundation follow-up

The implementation following commit 6c87383 adds an ESP-IDF application packaged by PlatformIO, a portable C++17 joint/configuration/actuator core, host fakes/tests and CI. See [Firmware/README.md](../Firmware/README.md) for build commands and restrictions. Explicit simulation enablement exists only in host tests; firmware cannot enable output. The exact board remains unverified, so its generic ESP32 target is compile-only and uploads are blocked.

Phase 1's software configuration and disabled-startup foundation is implemented; its original 37 host cases remain regression tests. ESP32 cross-compilation remains unverified because its toolchain download was interrupted after impractically slow transfer; this build gate remains outstanding (see the firmware verification snapshot). Physical geometry, board settings, calibration persistence/versioning and electrical validation are still unresolved; no hardware-ready claim is made. Geometry schemas are deferred until their mechanical inputs are established. The historical audit below remains a record of the pre-implementation tree, not a description of today's firmware files. The protocol subset is now implemented as described above; the cross-build gate still blocks hardware validation.

Audit date: 2026-10-02. Audited baseline: a94bafa (Update Progress Log for July 24, 2026). The working tree was clean before this documentation work. The audit covered all 42 tracked files: all text files were read; CAD and media were inventoried and hashed without modification. CAD binary internals, assembly constraints and image content were not engineering-validated.

## Historical architecture and development status (a94bafa)

The repository is a mechanical prototype and project-planning collection. The documented intended chain is dashboard -> Raspberry Pi -> ESP32 -> PCA9685 -> servos. There is no executable firmware, Pi service, computer-vision implementation or dashboard source. Firmware/README.md describes an intended home for ESP32 and Pi code, not code currently present.

README.md describes a single-leg prototype in development. Documents/Progress_Log.md, dated 2026-07-24, records coxa/femur completion, an assembly constraint fix, an incomplete assembly and a tibia still in progress. Those statements are more specific than the master specification's broad claim that leg CAD v1 and hardware selection are completed. No physical validation or software results are recorded. The historical word "Tomorrow" is not a current schedule.

The current user-supplied baseline is 6 legs, 3 DOF each, 18 MG996R servos, Raspberry Pi 4B, ESP32-WROOM-32U based development board, two PCA9685 controllers and camera-based vision. Procurement/installation status remains unverified. See [software architecture](SOFTWARE_ARCHITECTURE.md) for the proposed boundaries and configuration policy.

## Historical inventory and findings (a94bafa)

| Area inspected | Evidence and finding | Disposition |
| --- | --- | --- |
| README.md | Goals/team information remains useful; DevKit V1 and generic actuator/driver descriptions are outdated or underspecified | Correct only the hardware baseline and clarify software status; add links |
| All MASTER_SPECIFICATION.md files | Eight byte-identical copies in Ai/, CAD/, Dashboard/, Documents/, Electronics/, Firmware/, Images/, Videos/ | Preserve; designate current software baseline in docs/ and plan later consolidation |
| Historical hardware references | All eight masters use DS3218 and DevKit V1; Documents/MECHANICAL_REQUIREMENTS.md also uses these, including DS3218-specific fit and acceptance requirements | Current baseline supersedes these model references for software; mechanical fit/load revalidation required |
| Documents/COMPONENTS.md | One PCA9685, generic servo model, and planned/need-more procurement labels | Current baseline requires two controllers and 18 MG996R; do not treat old status as verified inventory |
| Documents/ELECTRONICS_ARCHITECTURE.md | Only a block chain; no schematic, bus addresses, pinout or power interfaces | Retain concept; wiring and electrical design TBD |
| Documents/HARDWARE_ARCHITECTURE.md | Whitespace-only placeholder | Leave intact; fill in a later hardware documentation task |
| Documents/POWER_SYSTEM.md | Outline labels only: battery, rails, converters, current/runtime | No validated power budget, sensing, protection or cutoff specification |
| Documents/MECHANICAL_REQUIREMENTS.md | Substantial design requirements: PETG, M3, below 5 kg, serviceability, clearances and fabrication | Preserve engineering work; do not confuse documented requirements with measured geometry or proof of feasibility |
| Documents/ROADMAP.md | Ten phase headings; master copies contain seven phases with different ordering/scope | Historical roadmaps lack software dependencies and acceptance gates; phased plan below governs proposed software work |
| Documents/Progress_Log.md | Repeated short and detailed July 24 status; explicitly incomplete assembly/tibia | Preserve as historical evidence; no need to deduplicate during this task |
| Firmware/ | Master copy and two-line README only | Missing source, board configuration, drivers, protocol, control/safety logic and tests |
| Computer_Vision/ | Directory absent | Feature/COMPUTER_VISION/1 and Ai/Ai are empty placeholders, not CV code |
| Dashboard/ | Master copy and whitespace-only Dashboard file | No application, API contracts or build; Images/ UI artwork is a concept asset |
| Electronics/ | Master copy and whitespace-only Electronics file | No electronics design files or verified harness map |
| Feature/ | CAD_REDESIGN/1, COMPUTER_VISION/1, DASHBOARD_UI/1, ESP32_FIRMWARE/1 are whitespace-only | Directory markers, not implementations; keep pending scoped cleanup |
| Ai/ | Duplicate master and whitespace-only Ai file | Naming overlaps proposed CV ownership; avoid two active implementations |
| Images/ and Videos/ | Four image assets, duplicate masters; no video assets tracked | Preserve all media; presence does not establish implemented functionality |
| Build/test/release infrastructure | No build manifests, dependency locks, tests, CI workflows, simulator, runtime configuration schemas, setup commands or .gitignore tracked | Add with the first real software slice; no software build/test can currently be run |

The eight master files share SHA-256 C8B2FEEB40C73100A46F31CE24B15AB33E9BA7BF1C8B68C4344309E9C8809726 at the audited baseline. There are 13 whitespace-only text placeholders: Ai/Ai, Assembly/README.md, four CAD subdirectory READMEs, Dashboard/Dashboard, Documents/HARDWARE_ARCHITECTURE.md, Electronics/Electronics, and the four Feature/*/1 files. Firmware/README.md and POWER_SYSTEM.md are minimal descriptions/outlines, not empty files.

## Historical CAD structure and preservation (a94bafa)

```text
CAD/
  MASTER_SPECIFICATION.md
  Coxa/   README.md, Spider_Robot_Coxa_V1.ipt, Spider_Robot_Coxa_V1.stl
  Femur/  README.md, Spider_Robot_Femur_V1.ipt, Spider_Robot_Femur_V1.stl
  Servo/  README.md, Servo Part 1.ipt, Servo Part 2.ipt,
          Servo Pin.ipt, Servo Pin.stl
  Tibia/  README.md only
Assembly/
  README.md
  Spider_Robot_Leg_Assembly_V1.iam
```

There are nine CAD/assembly binaries (five .ipt, three .stl, one .iam), no tracked .dwg, and four image assets. Recent history includes explicit deletion of the old tibia .ipt and .stl; do not restore obsolete models automatically. Assembly dependency resolution and MG996R compatibility remain unverified. No chassis model, final geometry table, print settings or completed six-leg assembly is present in the tracked inventory. Do not infer that current coxa/femur models fit MG996R without measuring/reviewing them.

This task preserves every existing engineering file and asset except the narrow README correction. Duplicate master documents remain unchanged intentionally. A later documentation consolidation should preserve unique requirements/history, choose one canonical engineering specification, replace duplicate copies with links, and update hardware references in a reviewed change. No CAD reorganization is required for software work.

## Conflicts and unresolved decisions

| Decision | Evidence/current resolution | Required evidence before use |
| --- | --- | --- |
| Servo model | User baseline MG996R replaces historical DS3218 | Physical dimensions, usable travel, installed limits and load testing |
| Controller quantity | User baseline two PCA9685 replaces COMPONENTS.md quantity one | Actual boards, unique addresses and harness continuity |
| ESP32 board | WROOM-32U based board replaces generic DevKit V1 reference | Exact board revision, pinout, USB interface and boot/output-enable behavior |
| Camera | Vision required; Camera Module 3 appears only in old masters | Confirm camera model/interface and calibration |
| IMU/ToF | README originally listed them without status | Optional planned sensors; exact models, necessity and wiring TBD |
| Mechanics | Six 3-DOF legs documented; tibia/assembly incomplete | Revisioned link lengths, joint axes, mounting transforms, collisions and mass/centre of mass |
| Power | LiPo mentioned historically; detailed power document is an outline | Battery/rails, current budget, protection, grounding, regulator capacity and physical cutoff TBD |
| Performance | No validated timing or runtime figures | Measure motion period, stop latency, serial budgets, vision throughput and power under load |
| Telemetry | Master promises battery percentage, speed, leg/servo status | Distinguish commanded/estimated data from measured feedback; unavailable until sensing exists |

No unresolved physical value should be filled with a plausible number. Keep documentation values TBD and future machine-readable values explicitly unresolved; fail configuration validation before hardware arming.

## Phased implementation and acceptance gates

### 0. Confirm interfaces and physical evidence

Record exact board/camera identities, wiring proposal, two-controller address plan, servo inventory and electrical power/cutoff design. Have the mechanical work provide revisioned geometry and verify MG996R fit. Software scaffolding can proceed with synthetic fixtures; physical motion cannot proceed with unresolved power, mapping or calibration.

Exit: reviewed interface checklist; every unresolved field is explicitly TBD with the measurement needed to resolve it. Historical documentation conflicts are visible, not silently copied into code.

### 1. Buildable software foundation (implemented subset; see follow-up above)

Create only the ESP32 application skeleton and portable control/configuration test harness from the proposed layout. Select and pin the ESP-IDF/toolchain version and exact board settings after board identification. Introduce geometry/wiring/calibration schemas, the 18 named joint IDs, fake servo/clock interfaces, a disarmed startup state, dependency/build metadata, .gitignore and CI. Real PWM output remains disabled.

Exit: documented clean-checkout host test command and firmware build command pass; tests reject missing geometry/calibration, duplicate channels and invalid values; fake output proves boot and invalid configuration cannot energize joints. CI runs the same commands. No walking, vision or full dashboard is part of this task.

### 2. Protocol and Pi control skeleton (host protocol subset implemented)

Freeze exact framing/CRC/field definitions and golden vectors. Implement bounded parsers on both sides, session handshake, freshness, idempotent stop/disarm, command arbitration and telemetry using simulated devices. Add Pi package metadata, pinned dependencies and service setup instructions.

Exit: cross-language golden-vector and integration tests pass for normal exchange, corruption, truncation, duplicates, stale/out-of-order packets, queue saturation, process restarts and link loss. No old motion resumes; ACK acceptance is distinguished from completion. Define timeout values based on measurements before live control.

### 3. One-servo output and calibration bench

Implement PCA9685 adapter, explicit OE handling and versioned calibration persistence. Validate board identity/channel routing and power design before a supported one-servo test. Measure frequency/pulse behavior and establish conservative limits rather than sweeping assumed endpoints.

Exit: recorded pulse measurements, channel identity and calibrated neutral/direction/limits for the test servo; power-on/reset/disconnect/fault behavior demonstrated; interrupted configuration writes fail safely. Physical cutoff is independently verified. Live testing follows a deliberate bench procedure.

### 4. One-leg kinematics and motion validation

After tibia/assembly geometry is reviewed, implement pure FK/IK and bounded joint trajectories. Calibrate the three installed servos, verify transforms and compare predicted/measured poses on a supported leg.

Exit: host tests cover reachability, singularities, mirrored conventions, branch continuity and limit rejection. Recorded bench results demonstrate collision-free operation within a documented envelope and repeatable stopping. Synthetic test dimensions never become robot defaults.

### 5. Six-leg mapping, stance and crawl gait

Verify all 18 channels and per-servo calibration, then implement stance/swing scheduling and controlled transitions. Validate chassis geometry, load capacity, centre of mass and power delivery. Start in simulation, then supported static stance, then slow crawl; defer tripod gait until justified.

Exit: no duplicate/missing joints; gait continuity/support checks pass; configured timeouts and fault stop policy pass under lost commands, partial I2C failure and Pi reboot. Record acceptable current, temperature, stability and motion envelope before unsupported walking. Thresholds remain TBD until engineering validation.

### 6. Operator dashboard and telemetry

Build a minimal UI over the Pi API: arm/disarm/stop, explicit mode/lease, connection freshness, faults and commanded posture. Add camera preview when capture works. Preserve existing visual assets; use them only as design references.

Exit: API authorization and lease expiry tests pass, browser disconnect stops refreshing operator commands, stale/unavailable values are labelled, and UI cannot bypass firmware limits or falsely show measured joint feedback.

### 7. Vision and bounded autonomous behavior

Implement camera acquisition and recorded-frame replay before detector/tracker integration. Benchmark on Pi 4B. Select model/runtime using measured accuracy, latency, memory and licensing. Keep autonomy behind the same arbiter as manual control; start with observation-only mode.

Exit: reproducible evaluation clips/metrics, bounded frame queues, stale-detection rejection and CPU-load isolation. Tracking/following requires a separately validated distance/obstacle strategy and operating envelope. SLAM, patrol and return-home remain later research work, not promised functionality.

## Verification of this documentation change

Review the complete staged diff, check local Markdown links and run git diff --check. Compare pre/post SHA-256 hashes of all nine CAD/assembly binaries and four images, and confirm that only AGENTS.md, README.md and the two new docs/ files changed. No executable tests exist at the audited baseline; documentation validation is not a hardware or software runtime test. Commit the four documentation files with a descriptive message after those checks.

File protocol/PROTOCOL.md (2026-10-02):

# Arachne-X command protocol v1

Status: host-tested reference protocol, physical actuator output locked. This protocol connects a Python Raspberry Pi reference client to a portable C++ ESP32-side endpoint. It does not implement the Pi robot service, a physical transport, gait, IK, autonomous navigation or vision. Existing firmware simulation/physical-output guards remain authoritative.

## Layers and ownership

`wire` encodes/decodes bounded frames without any transport or control dependency. `Endpoint` owns a stream parser, session/freshness state and the dispatcher. It calls the existing `ActuatorSystem` only after validation. A new const `validate_target()` permits all targets to be checked against the actuator's own immutable configuration; `emergency_stop()` only latches its existing fault state. No output path is added to the firmware build.

`Transport` provides nonblocking byte reads (Byte/Empty/Closed) and all-or-fail writes. `MemoryTransport` is a fixed-capacity duplex FIFO. An owner must call `Endpoint::poll()` regularly, including while idle, or call `tick()` between polls; no background task or timeout thread is created. Each poll consumes at most 281 bytes. Closed links, failed writes and backpressure invalidate the session and disable further commands. The physical owner-loop period remains TBD.

Python's equivalent transport has `write(bytes)` and `read(maximum)`. The small synchronous reference client allows one outstanding request and never retries commands automatically. A reply must be available when read is serviced; an empty read or incomplete/corrupt response raises an error rather than waiting indefinitely. Scheduling, asynchronous IO and real-link deadlines belong in a future adapter. Neither implementation imports UART, USB, network, Bluetooth or PCA9685 APIs. The host bridge's text/hex process interface is a test harness, not a proposed robot transport.

## Exact wire representation

All multibyte integers are unsigned little-endian. Joint targets are IEEE-754 binary64, little-endian, in **logical joint radians**, not PWM counts or servo pulses. Binary64 preserves the existing double-valued calibration endpoints without binary32 rounding past a configured limit. NaN/infinity and out-of-range values are rejected; there are no implicit units, travel limits or clipping rules.

The complete on-wire frame is `COBS(header || payload || CRC16) || 0x00`. COBS replaces zeros with block-length codes: a code 1-254 represents that many minus one following nonzero bytes and an implied zero between blocks; code 255 represents 254 nonzero bytes without an implied zero. Only the terminating delimiter is zero on the wire. Encoders are deterministic and shared golden vectors define exact examples.

| Decoded offset | Bytes | Field |
| --- | --- | --- |
| 0 | 1 | Protocol version, exactly 1 |
| 1 | 1 | Message type |
| 2 | 4 | Request ID/sequence |
| 6 | 8 | Receiver-issued session ID; zero means no active session |
| 14 | 4 | Receiver-issued freshness token; zero means unavailable |
| 18 | 2 | Payload byte length, 0-256 |
| 20 | length | Payload |
| 20 + length | 2 | CRC-16/CCITT-FALSE over header and payload, stored little-endian |

CRC parameters: polynomial 0x1021, initial 0xFFFF, no input/output reflection, final XOR 0x0000; `123456789` gives 0x29B1. CRC is corruption detection, not authentication. There is no packed C++ struct or dependence on native padding/endianness.

Maximum decoded size is 278 bytes; maximum encoded size excluding delimiter is 280; maximum wire frame is 281. Payload length must exactly match decoded size. There is no padding or accepted extra trailing payload. Unsupported versions, unknown types, malformed COBS, CRC errors, oversize and truncation are rejected before dispatch. Their headers are untrusted: they receive no ACK/NACK and increment a saturating diagnostic counter. Consecutive empty delimiters are ignored. Overflow discards input through the next delimiter; the parser then resynchronizes.

A stream fragment is incomplete until its delimiter arrives; it is not prematurely executed. Explicit end-of-stream or the configurable frame-assembly deadline identifies an unterminated frame as truncated, discards it and disables/invalidate the session. `Parser::finish()` exposes truncation even without a clock/transport. Firmware parser/dispatcher storage is fixed-size; no dynamic allocation is used in those layers.

## Commands and payloads

| Type | Name | Exact payload |
| --- | --- | --- |
| 1 | HELLO | Minimum supported version u8, maximum supported version u8 (2 bytes) |
| 2 | HEARTBEAT | Empty |
| 3 | GET_STATUS | Empty |
| 4 | ENABLE_REQUEST | Expected configuration revision/tag u32 (4 bytes) |
| 5 | DISABLE | Empty |
| 6 | SET_JOINT_TARGET | Joint ID u8, logical angle binary64 (9 bytes) |
| 7 | SET_MULTI_JOINT_TARGET | Count u8 (1-18), then count target records of 9 bytes (10-163 bytes) |
| 8 | EMERGENCY_STOP | Empty |

IDs 0-17 follow the architecture: LF coxa/femur/tibia, LM, LR, RF, RM, RR, each in that joint order. IDs outside this set are invalid. Each multi-target joint must be unique. All message payload lengths, identities, calibration states, finite numeric values and configured limits are checked before forwarding. Every multi-target entry passes preflight before any actuator command is called. Invalid batches forward zero commands. A subsequent simulated output/clock failure during an otherwise valid batch latches a fault; already accepted backend writes cannot be rolled back. This is atomic validation at the protocol/control boundary, not transactional physical PWM.

## Responses

Every response uses version 1 and echoes the exact request ID. Its session/token fields reflect the receiver's current state (zero after invalidation). Response types received by the embedded endpoint are rejected with WrongDirection; responses never execute as commands.

| Type | Name | Payload |
| --- | --- | --- |
| 128 | HELLO_ACK | Selected version u8, configuration tag u32, heartbeat timeout u64 microseconds, command/freshness timeout u64 microseconds, physical permission u8 (22 bytes) |
| 129 | ACK | Common outcome record, below |
| 130 | NACK | Common outcome record with nonzero error |
| 131 | STATUS | State/telemetry snapshot, below |
| 132 | HEARTBEAT_REPLY | Common outcome record; header contains newly issued token |

Common outcome (5 bytes): echoed command type u8; error u8; actuator state u8; fault u8; physical permission u8. ACK/HEARTBEAT_REPLY use error 0. A successful enable ACK means **request accepted** and its state may be **SimulationEnabled**; **physical permission is always 0**. The locked firmware build returns NACK/PhysicalLocked even for valid synthetic calibration. ACK is not measured motion completion. The Python client rejects a response that claims physical permission.

Actuator states: 0 Disabled, 1 SimulationEnabled, 2 Fault. Fault codes: 0 None, 1 EmergencyStop, 2 HeartbeatTimeout, 3 CommandTimeout, 4 Clock, 5 Transport, 6 Actuator. Timeout/transport diagnostics can be cleared by a fresh successful handshake; the actuator's latched Fault cannot. State and fault are separate: a timeout can report Disabled plus its timeout reason.

Error codes: 0 Ok; 1 BadPayload; 2 UnsupportedVersion; 3 WrongDirection; 4 NoSession; 5 BadSession; 6 BadSequence; 7 StaleToken; 8 NotConfigured; 9 ConfigMismatch; 10 Disabled; 11 PhysicalLocked; 12 InvalidJoint; 13 InvalidValue; 14 OutOfRange; 15 Uncalibrated; 16 InvalidConfiguration; 17 DuplicateJoint; 18 Stopped; 19 ActuatorFailure. The first failed validation determines the error. Envelope/state checks precede target checks. HELLO version-range disagreement receives error 2; an unsupported frame-header version is dropped by the decoder.

### STATUS layout (249 bytes)

| Payload offset | Bytes | Meaning |
| --- | --- | --- |
| 0 | 1 | Actuator state |
| 1 | 1 | Fault |
| 2 | 1 | Physical permission, always 0 |
| 3 | 1 | Whole actuator configuration valid, 0/1 |
| 4 | 1 | Active protocol session, 0/1 |
| 5 | 1 | Configured controller mask: bit 0 A, bit 1 B; not hardware health |
| 6 | 1 | Joint count, 18 |
| 7 | 4 | Configuration revision/tag; 0 means TBD |
| 11 | 4 | Malformed-frame counter, saturating u32 |
| 15 | 234 | 18 joint records, each 13 bytes, sorted by ID |

Each joint record: joint ID u8; configured controller u8 (0 A, 1 B, 255 unknown); configured channel u8 (0-15, 255 unknown); calibration-state flag u8; commanded-target-valid flag u8; last successfully accepted commanded angle binary64. The angle is ignored when its flag is zero (wire placeholder 0.0 does not imply a measured position). Calibration flags reflect records; the separate whole-configuration-valid flag must also pass. Values are commanded, never measured; the last command remains historical after disable/timeout. No current, voltage, torque, measured joint feedback or servo-health values are fabricated. Controller masks indicate mapping only; no I2C probing occurs.

## Sessions, ordering and freshness

HELLO negotiates version 1 through its min/max range, creates a new receiver-issued session/token, and always disarms an existing session. It never enables motion or clears E-stop. The owner supplies a nonzero fresh `session_seed` per endpoint lifetime; each successful handshake consumes the next u64 session number. This must be unique across restarts before physical deployment (generation/persistence/entropy method TBD). Counter exhaustion fails closed. Deterministic test seeds are explicitly synthetic and must not be reused as production boot identities.

The configuration tag is a nonzero, owner-assigned revision of the immutable actuator configuration, not a cryptographic hash or proof of mechanical calibration. It is returned in HELLO_ACK and must be echoed by ENABLE_REQUEST. Assignment and persistence in production remain TBD; a missing tag blocks handshake/enable. Changing configuration requires a new controller/session and revision. The client cannot mutate calibration over this protocol.

Except for HELLO, GET_STATUS, DISABLE and EMERGENCY_STOP, commands require the current session, strictly increasing u32 request IDs and the current token. Sequence wrap is not supported: start a new handshake/client. Syntactically valid commands consume their ID after session/sequence/token checks, even if semantic validation returns NACK. Duplicate/out-of-order requests are NACKed; they are never re-executed and no response cache or automatic retry is implemented. Loss of an ACK leaves command completion uncertain; query status or disable rather than replaying targets.

HELLO and successful HEARTBEAT issue tokens with receiver-monotonic deadlines. ENABLE/target messages require a token younger than `command_timeout_us`. A delayed previously unseen command cannot acquire a new validity window merely by arriving late. HEARTBEAT may renew the current token while its session is alive, even if that token aged out during a disabled idle period. Old tokens are rejected after rotation. Read-only GET_STATUS does not refresh heartbeat, token or motion deadlines or consume the control sequence.

DISABLE and EMERGENCY_STOP are accepted for any correctly framed version-1 empty-payload request, even without a handshake or with an old session/request ID/token. Both are idempotent and invalidate the session. GET_STATUS remains available before handshake and after E-stop. Frames still require valid length and CRC; corrupt stop packets cannot be safely interpreted.

## Timeouts and E-stop

`Settings` requires explicitly provided positive heartbeat, command/freshness and frame-assembly timeouts in microseconds, plus session seed and configuration tag. All default to unset/TBD. None is a production recommendation. The shared host fixture uses 1000/500/100 microseconds respectively solely to advance a fake clock deterministically.

- Startup and constructing an endpoint leave the actuator disabled.
- Missing configuration/clock prevents handshake and enable.
- Only valid current-session HEARTBEAT refreshes heartbeat liveness. Normal commands/status/corrupt packets do not.
- A successful explicit enable or accepted target batch refreshes the motion lease. Heartbeats never extend it.
- At `elapsed >= timeout`, heartbeat loss disables output forwarding and invalidates the session. An expired motion lease does the same while SimulationEnabled. No old motion resumes on reconnect; HELLO plus explicit enable is required.
- Clock unavailability/rollback, transport close/backpressure and partial-frame expiry also disable/invalidate. Status, DISABLE and E-stop remain available without a clock; no handshake or enable is possible until clock availability returns.
- E-stop latches `ActuatorState::Fault`, including in locked firmware. HELLO, heartbeat, enable and targets are then rejected. DISABLE, GET_STATUS and repeated E-stop remain available. `start()` and `disable()` cannot clear the latch. There is no wire reset/recovery message. Reconstructing an offline test process is an explicit new test lifecycle, not an automatic recovery policy. A physical recovery/reset design remains future work.

Physical permission remains false in every message and every build. The existing ESP32 compile guard rejects host-simulation flags; PlatformIO upload guards remain unchanged. No real backend exists. Software disable/E-stop does not cut servo power or stop previously programmed external hardware; verified OE/cutoff wiring and electrical/mechanical calibration remain prerequisites for a later hardware phase. CRC/session tokens are not protection against a malicious authenticated-looking sender; authorization and physical-link selection are still future work.

## Example exchange and tests

Logical example using synthetic fixtures: `HELLO(request=1, versions=1..1)` -> `HELLO_ACK(session=100, token=1, revision=7, physical=0)`; `ENABLE_REQUEST(request=2, session=100, token=1, revision=7)` -> `ACK(state=SimulationEnabled, physical=0)` on a simulation build, or `NACK(PhysicalLocked)` on the locked build. A target command must then pass the installed configuration's limits. `HEARTBEAT` rotates the token; future commands use the new token. `EMERGENCY_STOP` -> ACK with Fault/EmergencyStop and session 0; the next enable is rejected as Stopped.

[golden_vectors.txt](golden_vectors.txt) contains literal wire bytes for HELLO, a target and ACK. Both implementations encode and decode these same vectors; Python also verifies CRC with the independent standard-library `binascii.crc_hqx`. C++ tests exercise every payload length, corrupted/truncated packets, boundary validation, sessions, timeouts, E-stop, queue failure and fixed-seed malformed streams. Python tests exchange real encoded bytes with the actual C++ endpoint via host-only in-memory transport bridges, in both simulation and locked builds.

Run all tests using the CMake/CTest commands in [Firmware/README.md](../Firmware/README.md). Python 3.11+ is now required for the reference-client tests; only the standard library is used. There are no real-link, radio or serial dependencies and no tests energize hardware.

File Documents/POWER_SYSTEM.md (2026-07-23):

# Document:

Battery type
Voltage rails
Buck converters
Estimated current draw
Runtime estimates

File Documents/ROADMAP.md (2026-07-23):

## Phase 1 - Single Leg Prototype
## Phase 2 - Full Leg Validation
## Phase 3 - Chassis Design
## Phase 4 - Six-Leg Assembly
## Phase 5 - Camera Integration
## Phase 6 - Dashboard Development
## Phase 7 - AI Vision
## Phase 8 - Autonomous Navigation
## Phase 9 - Field Testing
## Phase 10 - Arachne-X V1

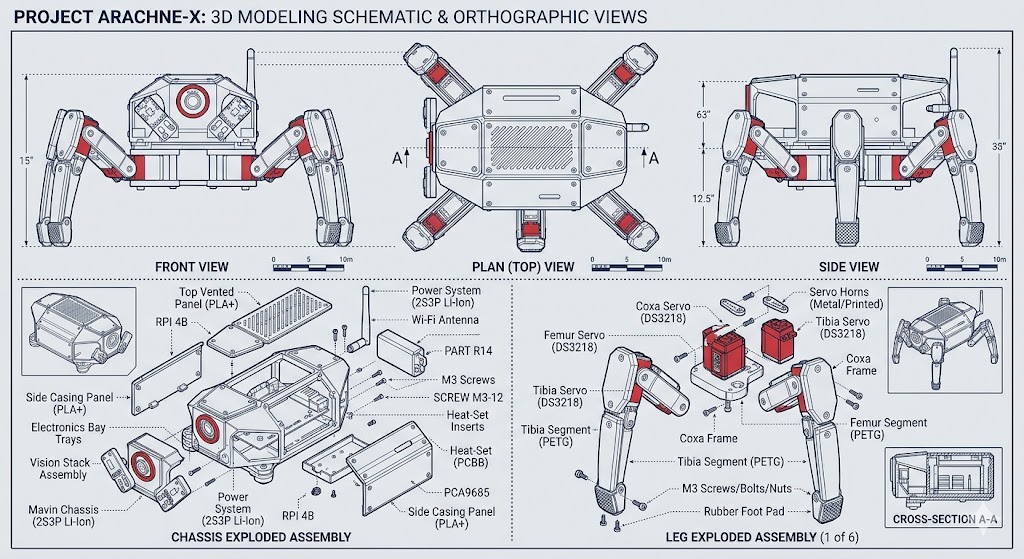
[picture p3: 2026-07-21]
Images/watermarked_img_6710523259164070452.jpg

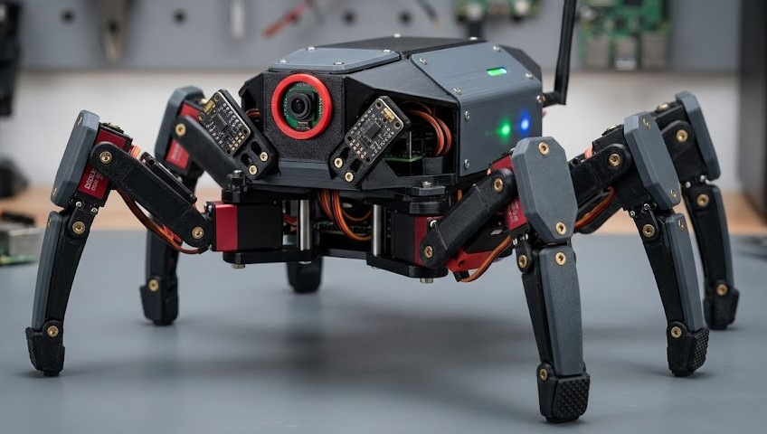
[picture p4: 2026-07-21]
Images/watermarked_img_6003007774428129105.jpg

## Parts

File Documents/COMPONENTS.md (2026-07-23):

| Component | Qty | Status |
| --- | --- | --- |
| Raspberry Pi 4B | 1 | Planned |
| ESP32 | 1 | Planned |
| PCA9685 | 1 | Planned |
| Servo | 18  | Need More |
| Camera Module | 1 | Planned |

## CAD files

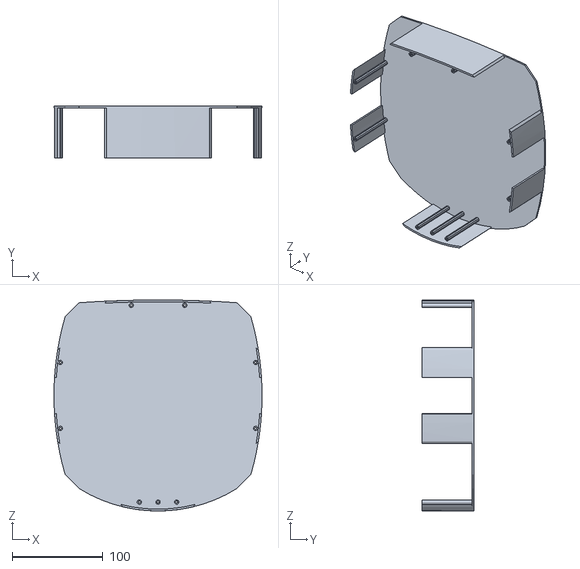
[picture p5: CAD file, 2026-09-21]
CAD/Chassis/Spider_Robot_Chasis_Top_V1.stl
229.5 x 57.0 x 232.9

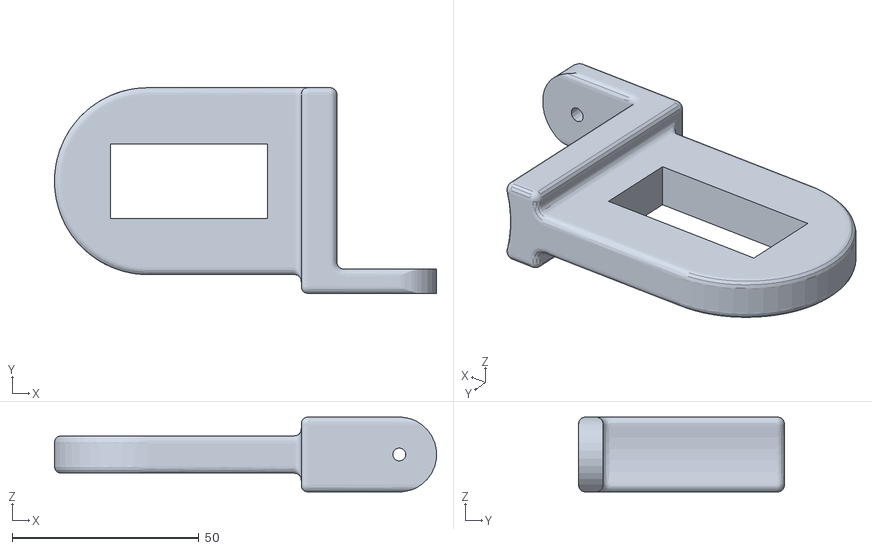
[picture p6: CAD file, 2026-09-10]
CAD/Coxa/Spider_Robot_Coxa_V1.stl
102.1 x 55.0 x 20.0

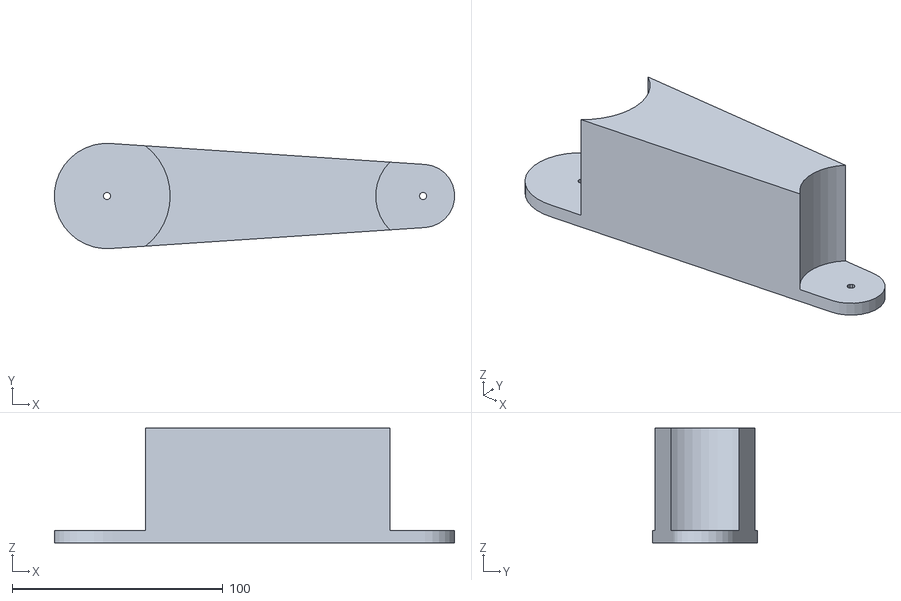
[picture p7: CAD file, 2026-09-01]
CAD/Femur/Spider_Robot_Femur_V1.stl
189.8 x 49.9 x 54.5

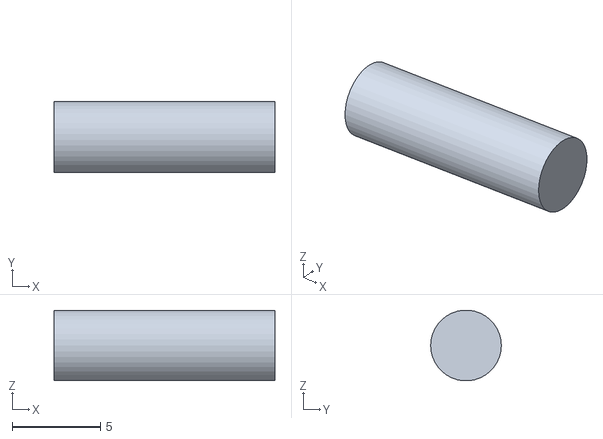
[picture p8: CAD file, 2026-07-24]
CAD/Servo/Servo Pin.stl
12.5 x 4.00 x 3.99

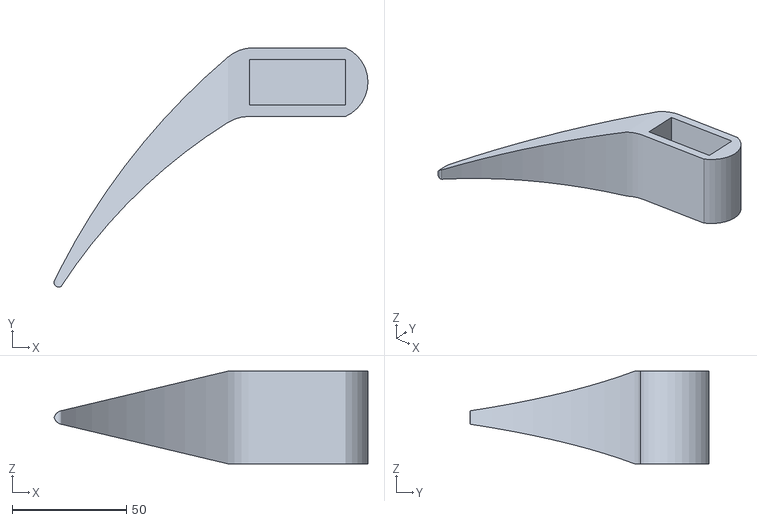
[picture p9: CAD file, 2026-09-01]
CAD/Tibia/Spider_Robot_Tibia_V1.stl
137.2 x 104.6 x 40.5

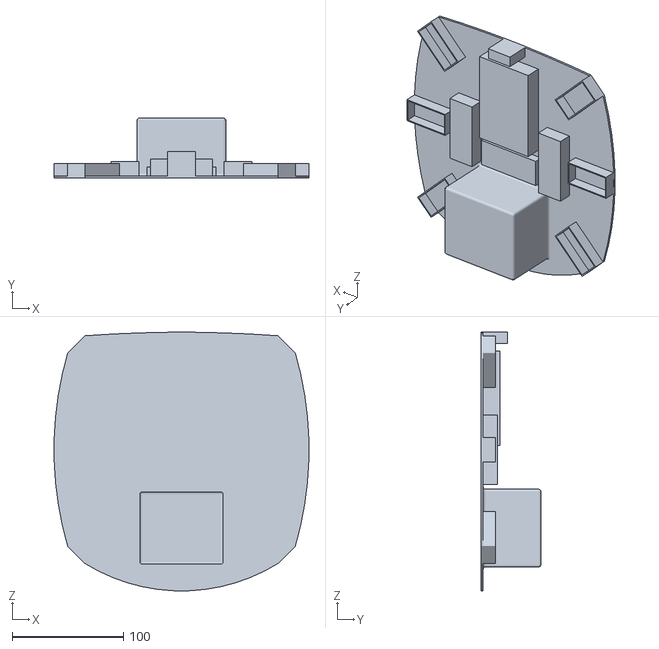
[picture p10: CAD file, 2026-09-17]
CAD/Chassis/Spider_Robot_Chasis_V1.stl
229.6 x 54.0 x 232.8

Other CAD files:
Assembly/Spider_Robot_Leg_Assembly_V1.dwg
Assembly/Spider_Robot_Leg_Assembly_V1.iam
CAD/Chassis/Spider_Robot_Chasis_Top_V1.ipt
CAD/Chassis/Spider_Robot_Chasis_V1.ipt
CAD/Coxa/Spider_Robot_Coxa_V1.ipt
CAD/Femur/Spider_Robot_Femur_V1.ipt
CAD/Servo/Servo Part 1.ipt
CAD/Servo/Servo Part 2.ipt
CAD/Servo/Servo Pin.ipt
CAD/Tibia/Spider_Robot_Tibia_V1.ipt

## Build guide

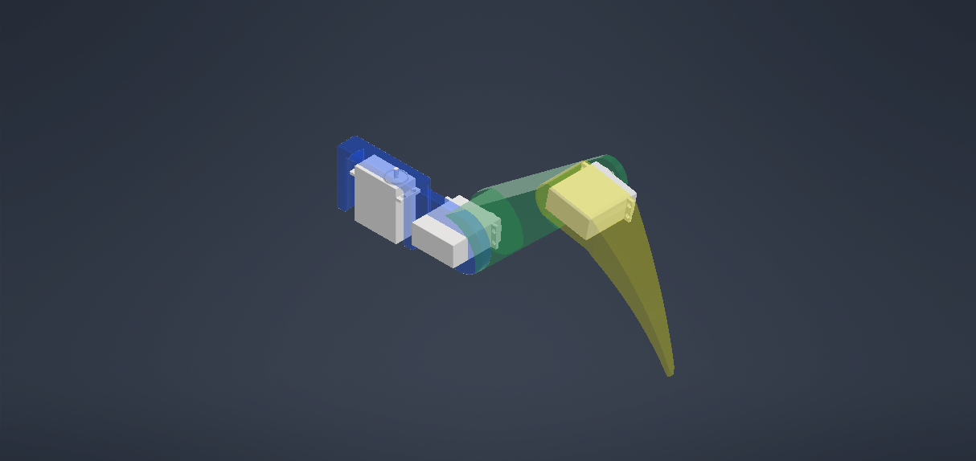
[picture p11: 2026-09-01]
Assembly/Spider_Robot_Leg_Assembly_V1.bmp

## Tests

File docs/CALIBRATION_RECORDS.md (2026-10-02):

# Calibration records and simulated persistence

This phase adds a portable C++17 record codec and persistence boundary in `Firmware/calibration/`. It does not calibrate physical servos. **Physical output remains compiled out, boot remains disabled, and valid records do not enable motion.** Protocol v1, its wire format and the Python reference client are unchanged; there are no remote calibration commands.

## Representation and evidence

`Record` holds a complete `RobotConfiguration`, three externally supplied positive revision IDs, provenance, an optional externally supplied Unix timestamp in seconds, and optional method/approval evidence IDs. Each of the 18 joints retains its logical identity, controller/channel, direction, calibration state, angle minimum/neutral/maximum in radians and pulse minimum/neutral/maximum in microseconds. Pulse points must be retained to restore the existing configuration completely; none is derived from assumed MG996R specifications.

Default construction provides named but unconfigured joints, unset calibration values, zero (unresolved) revisions and `Unapproved` provenance. Incomplete drafts can exist in memory but cannot be serialized or committed by this codec. No production calibration fixture is included.

Three independent questions must pass:

1. **Format/integrity:** expected size, magic, version, reserved fields, metadata encoding and CRC.
2. **Configuration:** the existing validator checks all 18 identities, unique controller/channel pairs, enums, calibration states, finite values, strict min/neutral/max relationships and required fields. `Report` exposes format/configuration flags and the existing bounded joint diagnostics. Format-valid bytes can still contain invalid configuration.
3. **Evidence/policy:** a complete configuration is not proof of physical calibration. `Unapproved` records cannot become committed snapshots through `Repository`. `SyntheticTest` requires explicit `AllowSyntheticForHostTests`; ESP32 compilation rejects synthetic loading regardless of that policy. `PhysicalApprovalClaim` requires positive externally supplied method and approval IDs. These are references to an external review, **not verified evidence, a cryptographic signature, or permission to actuate**. A claimed `Calibrated` flag alone is insufficient.

The default loading policy requires a physical approval claim. The host tests explicitly mark their records synthetic and reuse the existing asymmetric arithmetic fixtures. Tests of approval handling use clearly labelled synthetic evidence IDs; they do not establish robot calibration. There is no automatic conversion of synthetic provenance to physical approval.

## Schema v1: exact binary layout

The record is exactly **998 bytes**: 40-byte header, 18 rows of 53 bytes, and 4-byte CRC. Integers are unsigned little-endian. Numeric calibration values are IEEE-754 binary64, little-endian, matching the existing configuration type. No native C++ structure padding is persisted. Encoding sorts rows by logical joint identity; caller slot order does not affect bytes. Decoding accepts any row order if the complete configuration validates and all identities are unique.

| Offset | Size | Meaning |
| --- | --- | --- |
| 0 | 4 | ASCII `AXCR` |
| 4 | 2 | Schema version, 1 |
| 6 | 2 | Total record length, 998 |
| 8 | 4 | Configuration revision, nonzero |
| 12 | 4 | Geometry revision, nonzero |
| 16 | 4 | Hardware/wiring revision, nonzero |
| 20 | 1 | Timestamp present flag, 0 or 1 |
| 21 | 1 | Provenance: 0 Unapproved, 1 SyntheticTest, 2 PhysicalApprovalClaim |
| 22 | 1 | Joint count, exactly 18 |
| 23 | 1 | Reserved, must be 0 |
| 24 | 8 | Unix timestamp seconds; zero when absent; present zero is distinguishable |
| 32 | 4 | Method/notes identifier, 0 means absent |
| 36 | 4 | Approval evidence identifier, 0 means absent |
| 40 | 954 | 18 joint rows |
| 994 | 4 | CRC-32 over bytes 0 through 993 |

Each joint row has these offsets relative to its start:

| Offset | Size | Meaning |
| --- | --- | --- |
| 0 | 1 | Joint ID 0-17: LF, LM, LR, RF, RM, RR; coxa/femur/tibia within each leg |
| 1 | 1 | Controller: 0 A, 1 B |
| 2 | 1 | Channel: 0-15 (device domain, not a selected harness map) |
| 3 | 1 | Direction: 0 Normal, 1 Inverted |
| 4 | 1 | Calibration state: 0 Uncalibrated, 1 Calibrated; uncalibrated fails configuration validation |
| 5, 13, 21 | 8 each | Minimum, neutral, maximum logical angle, radians |
| 29, 37, 45 | 8 each | Minimum, neutral, maximum pulse, microseconds |

Integrity uses **CRC-32/ISO-HDLC**: polynomial 0x04C11DB7 (reflected implementation 0xEDB88320), initial 0xFFFFFFFF, reflected input/output, final XOR 0xFFFFFFFF, checksum stored little-endian. `123456789` yields 0xCBF43926. CRC covers metadata and every joint field. It detects accidental corruption, not tampering or forged approval. Authentication and trusted evidence management remain future requirements before deployment.

Wrong size, truncation, trailing bytes, bad CRC, unknown schema, unresolved revisions, unknown provenance, noncanonical timestamp flags and nonzero reserved bytes are rejected. Configuration problems are returned as joint diagnostics. An unsupported schema is rejected, never guessed or silently migrated. Encode/decode output arguments remain unchanged on failure. All codec buffers and reports are bounded; no heap allocation is required.

## Lifecycle and activation boundary

`Repository` is single-owner and noncopyable, associated with a `Storage`, expected revisions and the existing `ActuatorSystem` safety interface. It exposes these states:

| State | Meaning |
| --- | --- |
| Absent | No usable snapshot, or explicitly invalidated; no implied default calibration |
| Candidate | A complete record has been staged but is not committed or available as a snapshot |
| Validated | Read-back bytes passed integrity, configuration, revision and provenance checks; still no snapshot |
| Committed | Committed bytes were read and revalidated; an immutable public snapshot is available |
| Rejected | An operation failed; no usable snapshot is exposed |

Normal sequence: `stage(record)` -> `validate_candidate()` -> `commit()`. A commit cannot skip validation. Unapproved data may be staged for inspection but fails the eligibility check. A successful commit publishes a snapshot only after reading and checking committed storage again. `load()` checks committed bytes only; it never promotes an abandoned candidate, even if that candidate was validated before interruption. `interrupted_candidate()` identifies pending bytes from an interrupted/abandoned transaction; incomplete candidate writes also return an error. There is no automatic retry.

Construction, staging, validation, commit, load and invalidation disarm the associated actuator and never send output. Rejection clears the repository snapshot; it does not partially overwrite the actuator's immutable configuration. `disable()` cannot clear an existing actuator fault, so E-stop stays latched throughout these operations.

The only restored configuration is `repository.snapshot()->configuration()` after a successful load/commit. It is const through the public API. An owner may use it to construct an explicit new **disabled** actuator lifecycle; the existing actuator remains unchanged. There is no live configuration swap, auto-enable, reboot hook or fault recovery mechanism. Owners must not reconstruct an actuator to bypass an existing fault. This phase does not wire storage loading into `app_main`; firmware remains inert. Keeping an old snapshot does not establish that its revisions remain suitable after a hardware change.

## Atomic storage contract

`Storage` abstracts staging, candidate reads, `commit(expected_bytes)`, committed reads and pending-candidate presence. It has no NVS, filesystem, flash, SD, Pi storage, GPIO or bus dependency. The contract requires:

- Candidate writes never modify committed bytes, including on interruption.
- Reads return complete bytes or fail; malformed complete data is rejected by the codec.
- Commit succeeds only for the exact candidate that was validated. Publication is all-or-nothing; a failed commit preserves the previous committed record.
- The previous record remains authoritative until the atomic commit boundary. A crash after that boundary can expose the complete new record; a crash before it exposes the old record.
- A future physical adapter must independently prove durability and atomicity, including its synchronization/commit marker and power-loss behavior. The interface alone cannot guarantee real flash behavior.

`MemoryStorage` implements this contract for a single host thread with separate candidate and committed byte buffers. It offers deterministic interrupted-write, failed-commit, failed-read and corruption injection. Data survives repository destruction/recreation while the storage object lives, **not host process exit**. It is guarded against inclusion on ESP32. No physical storage implementation is selected.

Last-known-good recovery means explicitly loading the untouched previous commit after a failed write/commit. No abandoned candidate is activated. If committed bytes themselves are corrupt or mismatch current revisions, loading fails closed; the implementation does not silently revert to a potentially obsolete calibration. The storage simulation does not retain a multi-generation archive.

## Revision changes and remaining TBDs

`Revisions` carries configuration, geometry and hardware/wiring IDs. Values are positive owner-assigned identifiers; zero means unresolved and blocks serialization/loading. This is a software record contract, **not an invented CAD revision naming scheme**. Assignment, mapping to actual CAD/hardware, persistence and evidence provenance remain TBD. The caller must supply expected IDs; the library does not discover physical changes.

Servo/horn replacement, remapping, geometry changes or changed calibration require the responsible owner to assign relevant new revision IDs and call `invalidate(new_expected)`. Invalidation disarms and drops the active snapshot without deleting old committed bytes. Those bytes then fail revision checks. Resubmission requires the complete candidate/validation/commit sequence. Do not reuse IDs for physically different configurations. The configuration revision can identify the matching immutable protocol configuration tag, but no automatic protocol update or new wire command is added here.

Actual wiring, directions, angles, pulse ranges, neutral offsets, hardware approval procedure, evidence authenticity, revision registry, storage hardware, power-loss durability, wear policy, geometry and cutoff design all remain TBD. No numeric robot calibration is supplied. Valid persisted bytes cannot establish mechanical clearance, load capability, wiring correctness or power safety; physical servo output remains unavailable.

## Validation and reproduction

Use the host commands in [Firmware/README.md](../Firmware/README.md). CTest now includes `calibration_tests` and `calibration_locked_tests` alongside the original five suites; the existing CI host job discovers all seven automatically. No additional Python packages are required.

Verified locally on 2026-10-02 from starting commit `4d14f5317edad2339ed38934f25a12bffd339b41`: MSVC 19.51.36260.0 Release build passed with /W4 /WX, and **131/131 cases across seven suites** passed: original 33 control + 4 locked + 29 protocol + 2 protocol-locked + 29 Python/integration, plus 32 calibration + 2 calibration-locked. The initial build caught a signed/unsigned comparison in a new test; it was corrected before the successful run. The ESP32/simulation compile guard and upload guard passed. Existing protocol implementation and all prior tests remain unchanged.

Calibration robustness includes 7,984 individual bit flips, all 998 truncation points, interruption at all 998 candidate-write boundaries, and 2,000 random inputs plus 2,000 checksum-repaired mutations. A checksum-repaired mutation may represent valid alternate data; it must still pass all configuration checks. Tests cover revision/provenance rejection, no partial result, last-good recovery, full replacement, E-stop and physical lock. No hardware was used. ESP32 cross-compilation remains unverified because the SDK/compiler are unavailable; repeated toolchain downloads were not attempted.

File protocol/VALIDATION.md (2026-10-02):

# Protocol phase validation (2026-10-02)

Starting commit: 7d2f00e. Tests use simulated endpoints only; physical permission is false.

## Executed locally

Windows x64, MSVC 19.51.36260.0, CMake 4.3.1-msvc1; CMake selected Python 3.14.0 for the Python suite. Release compilation passed with project warnings treated as errors (/W4 /WX), with no compiler warnings/errors. Commands from the repository root (using the installed CMake executable's full path because it is not on PATH):

```sh
cmake -S Firmware -B Firmware/build-host -DARACHNE_HOST_TESTS=ON
cmake --build Firmware/build-host --config Release --parallel
ctest --test-dir Firmware/build-host -C Release --output-on-failure
```

CTest: **5/5 suites passed, 97/97 named cases**:

| Suite | Cases passed |
| --- | --- |
| Existing control_tests | 33/33 |
| Existing locked_tests | 4/4 |
| New protocol_tests | 29/29 |
| New protocol_locked_tests | 2/2 |
| Python codec/client + actual C++ endpoint integration | 29/29 |

The robustness cases include every payload length 0-256 with zero/nonzero patterns, 10,000 fixed-seed random streams per C++/Python parser, all single-bit corruptions of an enabled-session target frame in C++, and 100 random streams through the Python/C++ process bridge. Shared literal vectors pass both codecs; Python checks their CRC using independent stdlib binascii.

Verified: disabled startup; no implicit enable; locked-build enable rejection; physical permission always false; full-batch preflight rejection; malformed packets produce no actuator writes; replay/stale-token rejection; heartbeat and command expiry; frame truncation/expiry; closed/full transports; explicit E-stop persistence across start/disable/HELLO; no automatic motion recovery. Existing ESP32/simulation compile-conflict checks pass, and the Python suite executes five isolated upload-guard checks without running an upload tool. The original upload script, PlatformIO configuration, fake hardware and ESP32 entry-point source are unchanged.

## Limits

The SDK and Xtensa compiler remain absent from the local PlatformIO packages. The previous phase documented impractically slow downloading. Per this task's instruction, the download/cross-build was not repeated. **ESP32 cross-compilation remains unverified.** The registered protocol component was compiled in both locked and simulation host variants. The committed GitHub Actions workflow runs the full host suites on Linux/Windows and attempts a compile-only ESP32 build, but GitHub Actions was not executed in this local session.

No physical tests, serial ports, GPIO, I2C or servo output were used. No production timing, mechanical dimensions, addresses, pins, pulse ranges, joint limits or calibration were established. CRC/session freshness does not provide authentication; external clock scheduling, unique boot namespaces, configuration revision management and hardware stop/cutoff remain deployment prerequisites. See [the specification](PROTOCOL.md).

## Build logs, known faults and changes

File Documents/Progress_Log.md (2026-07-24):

# 2026-07-24

Completed:
- Coxa
- Femur
- Assembly fixed

## Progress Update (2026-07-24)

## Completed
- Designed the Coxa component.
- Designed the Femur component.
- Fixed the assembly constraint issue.
- Added the Coxa and Femur Inventor files to the repository.
- Added the current (incomplete) assembly.

## In Progress
- Tibia model.
- Complete one fully assembled leg.

## Next Steps
- Finish the Tibia.
- Verify full range of motion.
- Check for collisions between parts.
- Prepare the leg for duplication across the robot.

## Notes
- The assembly in the repository is not yet complete.
- The Coxa and Femur are the latest versions and should be used going forward.

Tomorrow:
- Tibia
- Complete one leg

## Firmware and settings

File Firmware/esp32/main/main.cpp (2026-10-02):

#include "arachne/actuator.hpp"

// Deliberately no GPIO, I2C, PWM, serial, tasks, or hardware initialization.
// Returning from app_main is supported by ESP-IDF. Firmware stays inert.
extern "C" void app_main() {
    static arachne::DisabledOutput output;
    static arachne::UnavailableClock clock;
    static const auto config = arachne::unconfigured_robot();
    static arachne::ActuatorSystem actuators(config, output, clock);
    actuators.start();
}

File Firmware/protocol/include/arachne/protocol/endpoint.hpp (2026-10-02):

#pragma once
#include "arachne/actuator.hpp"
#include "arachne/protocol/transport.hpp"

namespace arachne::protocol {
enum class Error : std::uint8_t {
    Ok = 0, BadPayload = 1, UnsupportedVersion = 2, WrongDirection = 3, NoSession = 4, BadSession = 5,
    BadSequence = 6, StaleToken = 7, NotConfigured = 8, ConfigMismatch = 9, Disabled = 10, PhysicalLocked = 11,
    InvalidJoint = 12, InvalidValue = 13, OutOfRange = 14, Uncalibrated = 15, InvalidConfiguration = 16,
    DuplicateJoint = 17, Stopped = 18, ActuatorFailure = 19
};
enum class Fault : std::uint8_t {
    None = 0, EmergencyStop = 1, HeartbeatTimeout = 2, CommandTimeout = 3, Clock = 4, Transport = 5, Actuator = 6
};
struct Settings {
    std::optional<std::uint64_t> heartbeat_timeout_us;
    std::optional<std::uint64_t> command_timeout_us;
    std::optional<std::uint64_t> frame_timeout_us;
    // Deployment must supply a fresh boot/session namespace and a revision tied
    // to the immutable actuator configuration. No production defaults exist.
    std::optional<std::uint64_t> session_seed;
    std::optional<std::uint32_t> configuration_tag;
};

class Endpoint {
public:
    Endpoint(ActuatorSystem& actuators, const Clock& clock, Settings settings);
    Endpoint(const Endpoint&) = delete;
    Endpoint& operator=(const Endpoint&) = delete;
    void poll(Transport& transport); // bounded: at most kMaxWire input bytes
    void tick(); // must also be called when there is no traffic
    void disconnect();
    Fault fault() const;
    bool session_active() const { return active_; }
    std::uint32_t malformed_count() const { return malformed_; }
private:
    Frame dispatch(const Frame& request);
    Frame reply(const Frame& request, Type type) const;
    Frame outcome(const Frame& request, Error error, Type success = Type::Ack) const;
    Frame status(const Frame& request) const;
    void invalidate(Fault reason);
    bool configured() const;
    void record_error();
    ActuatorSystem& actuators_;
    const Clock& clock_;
    const Settings settings_;
    Parser parser_;
    bool active_{false};
    Fault fault_{Fault::None};
    std::uint64_t session_{0}, next_session_{0};
    std::uint32_t sequence_{0}, token_{0}, malformed_{0};
    std::optional<std::uint64_t> last_clock_, partial_since_;
    std::uint64_t heartbeat_at_{0}, command_at_{0}, token_at_{0};
    std::array<std::optional<double>, kJointCount> commanded_{};
};
} // namespace arachne::protocol

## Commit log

2026-07-21 Create CAD
2026-07-21 Enhance README with project details and status
    Expanded the README with project goals, hardware specifications, and current status.
2026-07-21 Create CAD Files
2026-07-22 Document Arachne-X project specifications
    Added detailed project specifications for Arachne-X, including vision, hardware components, leg architecture, dashboard features, and future expansion plans.
2026-07-23 Create ├── MASTER_SPECIFICATION.md ├── ROADMAP.md ├── COMPONENTS.md ├── MECHANICAL_REQUIREMENTS.md ├── ELECTRONICS_ARCHITECTURE.md └── POWER_SYSTEM.md
2026-07-23 Create ├── MASTER_SPECIFICATION.md ├── ROADMAP.md ├── COMPONENTS.md ├── MECHANICAL_REQUIREMENTS.md ├── ELECTRONICS_ARCHITECTURE.md └── POWER_SYSTEM.md
2026-07-23 Add sections for battery and power system details
2026-07-24 Update Progress Log for July 24, 2026
    Added a progress update for July 24, 2026, detailing completed tasks, ongoing work, next steps, and notes on the assembly.
2026-07-25 Enhance camera test with FPS and UI elements
    Added FPS counter, crosshair, and status text to camera feed.
2026-07-25 Update Camera Test script with new features
2026-07-25 Display operator name in camera feed
    Added operator name display to the camera feed.
2026-07-25 Refactor Camera_Test.py with color constants
2026-07-25 Enhance pixel reader with crosshair and color info
    Added crosshair and pixel color display in the frame.
2026-07-27 Refactor camera loop exit condition and text positioning
    Updated the exit condition for the camera loop to use a variable for the kill key. Adjusted text positioning for better visibility.
2026-08-22 First draft of the basic dashboard (it's very simple), analog sticks, camera streaming will be added when the hardware is ready.
2026-08-29 Implement contour area filtering in motion detection
    Added area check to filter out small contours in motion detection.
2026-10-02 feat(firmware): add disabled ESP32 foundation and host safety tests
2026-10-02 feat(protocol): add host-tested Pi ESP32 command and telemetry protocol
2026-10-02 feat(calibration): add versioned records and atomic simulated persistence
